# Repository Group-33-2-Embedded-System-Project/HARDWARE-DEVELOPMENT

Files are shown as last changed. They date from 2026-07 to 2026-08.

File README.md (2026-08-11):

# Smart Coop Predator Deterrent — ESP32 Edition

A self-contained, WiFi-connected predator deterrent for chicken coops. The ESP32 runs a local HTTP + WebSocket API — **no backend, no MQTT broker, no cloud**. A companion mobile app connects directly to the device over your home WiFi.

The system arms automatically at night, watches for motion with radar + PIR, escalates through CLEAR → CAUTION → DANGER → ALERT, and fires a two-tone siren + red strobe + 8×8 matrix display. Everything is visible on the device itself; the app is for remote monitoring and control.

---

## 1. Project Files

| File | Purpose |
|---|---|
| `diagram.json` | Wokwi circuit diagram (ESP32 + all sensors/actuators wired) |
| `smart_coop_deterrent.ino` | Main firmware |
| `libraries.txt` | Wokwi library auto-install list |
| `scpd-mobile/App.js` | React Native / Expo companion app |
| `README.md` | This file |

All four files must sit in the **same project folder** (whether that's a Wokwi project
or a local Arduino sketch folder).

### Revised 3D enclosure

The original root-level STL exports are legacy files and are substantially oversized.
The editable compact replacement is in [`enclosure/`](enclosure/):
`smart_coop_enclosure.scad` generates a 104 × 78 × 30 mm base and a matching fitted
lid. The design uses 1.8 mm walls, a 1.6 mm floor/lid, M2.5 screw bosses, a
MAX7219 display aperture, a cable exit, and print-friendly ventilation. Component
envelopes, tolerances, and export instructions are in `enclosure/DIMENSIONS.md`.

---

## 2. Hardware / Bill of Materials
---

## 2. Hardware / Bill of Materials

- ESP32 DevKit V1
- RCWL-0516 microwave radar sensor
- HC-SR501 (or similar) PIR motion sensor
- LDR module with digital `DO` output (LM393-style)
- 8×8 LED matrix — **MAX7219 / 1088AS** (DIN → GPIO 5, CS → GPIO 17, CLK → GPIO 18)
- Passive buzzer → GPIO 26
- Red alert LED (through 220 Ω) → GPIO 25
- WiFi status LED → GPIO 2
- Pushbutton (manual trigger) → GPIO 32
- 5 V regulated supply for the matrix (≥ 4 A recommended); common GND with ESP32

> **Note:** The matrix is driven with a small built-in MAX7219 `shiftOut` driver — no extra NeoPixel/Adafruit_NeoPixel library needed. A 74AHCT125 level shifter on the matrix data line is recommended for reliable real-world operation.

---

## 3. Pinout (ESP32 DevKit V1)

| Component | Pin | Notes |
|---|---|---|
| RCWL-0516 OUT | GPIO 4 | 3.3 V-tolerant radar output |
| PIR OUT | GPIO 27 | digital input |
| Pushbutton | GPIO 32 | `INPUT_PULLUP`, other leg to GND |
| LDR DO | GPIO 34 | digital input; adjust the module trimmer for your dark threshold |
| Matrix DIN | GPIO 5 | MAX7219 data |
| Matrix CS | GPIO 17 | MAX7219 chip-select |
| Matrix CLK | GPIO 18 | MAX7219 clock |
| Buzzer | GPIO 26 | passive buzzer + GND |
| Red alert LED | GPIO 25 | through 220 Ω |
| WiFi status LED | GPIO 2 | through 220 Ω |
| Battery voltage sense | GPIO 35 | optional analog input |

---

## 4. Firmware Behavior

### 4.1 Arming
The system is **armed at night** (LDR = dark). The mobile app can also force `auto` / `on` / `off`.

### 4.2 Threat Levels

| Level | Trigger | Matrix | Red LED | Buzzer |
|---|---|---|---|---|
| **CLEAR** | No motion | Green breathing moon | OFF | OFF |
| **CAUTION** | Radar only, sustained ≥ 2 s | Yellow border + inner pulse | Solid | OFF |
| **DANGER** | PIR + radar simultaneous | Orange frame + flashing crosshair | Solid | OFF |
| **ALERT** | Deterrent actively firing | Red blinking alarm (~2 Hz) | Fast strobe | Two-tone 2.5 kHz / 1.2 kHz |
| **BOOTING** | WiFi not yet connected | Blue rotating spinner | OFF | OFF |
| **OFFLINE** | WiFi lost after connect | Normal threat glyph + blinking blue corner pixel | — | — |

- Matrix brightness auto-adjusts to ambient light (LDR): dim in darkness, bright in daylight, full during ALERT.
- Button press: manual trigger + white flash acknowledgement on matrix.
- Component toggles (radar, PIR, deterrent, matrix, buzzer) are available from the app and respected by the firmware immediately.

### 4.3 Radar hold
A detection is held for **4 seconds** (`RADAR_HOLD_MS`) after the last radar HIGH so the CAUTION state and the app’s radar dot stay visible instead of flickering off.

---

## 5. Mobile App Connection (No Backend)

The app (`scpd-mobile/App.js`) is a React Native / Expo app. It discovers and talks to the ESP32 **directly** — no cloud, no broker.

### 5.1 Discovery
1. Tries mDNS: `coop-plus.local`, `smart-coop.local` (best on iOS; Android may require manual IP).
2. Scans a few common static IPs.
3. Scans the **phone’s actual WiFi subnet** (requires `expo-network`).
4. If discovery fails, enter the ESP32’s IP manually (shown in Serial Monitor at 115200 baud).

### 5.2 Live Communication
- **HTTP REST:** `GET /api/status`, `POST /api/commands/deterrent`, `POST /api/commands/arm`, `POST /api/commands/toggle_component`, `DELETE /api/events`, `DELETE /api/events/<id>`
- **WebSocket:** `ws://<host>:80/ws` pushes live status updates.

Both run on **port 80**. The phone and ESP32 must be on the **same LAN**.

---

## 6. Quick Start

### Wokwi (simulation)
1. Open the project in Wokwi.
2. Ensure `diagram.json`, `smart_coop_deterrent.ino`, and `libraries.txt` are present.
3. Press Play. Wokwi auto-installs the listed libraries.

### Real hardware (Arduino IDE / CLI)
1. Install the ESP32 board package (Espressif Systems).
2. Select **ESP32 Dev Module** (or your board).
3. Place `smart_coop_deterrent.ino` in a folder named `smart_coop_deterrent`.
4. Edit the WiFi block at the top of the sketch with your SSID and password.
5. Upload; open Serial Monitor at **115200 baud** to watch the connection logs and the printed local IP.

### Mobile app
```bash
cd scpd-mobile
npx expo install expo-network   # required for subnet-aware discovery
npx expo start
```
Scan the QR with Expo Go (or run on a simulator). Tap **Connect**; if auto-detect misses, type the ESP32’s IP manually.

---

## 7. Serial Test Commands

With the ESP32 connected to Serial Monitor (`115200` baud, `NL + CR` or line ending set appropriately):

| Command | Effect |
|---|---|
| `help` | Print this menu |
| `status` | Full system status report |
| `led` | Blink the red alert LED 3× |
| `buzzer` | 2-second buzzer test |
| `matrix` | Cycle through all matrix states |
| `telemetry` | Live sensor stream |
| `ldr_calib` | Calibrate LDR dark threshold |

---

## 8. Troubleshooting

| Symptom | Likely cause / fix |
|---|---|
| App can’t discover the device | Phone and ESP32 are on different subnets, or AP/client isolation is on. Enter the ESP32’s IP manually (shown in Serial Monitor). |
| App connects but “Connecting…” flickers / kicks back to Home | Auto-reconnect now runs silently in the background; reload the app. If it persists, the firmware’s WiFi is flapping — check signal strength. |
| Matrix is blank / wrong size | Confirm DIN/CS/CLK wiring and that the matrix is powered from a separate 5 V supply, not the ESP32’s USB pin. |
| Buzzer quiet or clicking | Passive buzzer on GPIO 26 + GND. If using an active buzzer, the pitch sweep won’t work — swap to passive. |
| Deterrent never fires | Check `armed` state (Serial `status`), LDR dark threshold, and that radar/PIR toggles are enabled in the app. |
| Events/activities not clearing | Use the trash icon on individual events, or the **Clear** button in History. Both now hit firmware endpoints and refresh automatically. |

---

## 9. Design Notes (for the poster / reviewers)

- **No cloud dependency.** The ESP32 hosts its own API; the phone talks to it directly. If the internet goes down, the coop still works locally.
- **Sensors are toggleable.** Radar, PIR, deterrent, matrix, and buzzer can all be switched off from the app — useful for testing or quiet hours.
- **8×8 matrix is the primary local HCI.** Color code: green = safe, yellow = caution, orange = danger, red = alert, blue = booting/offline. The red LED stays solid for any active threat and strobes only while the siren fires.
- **Radar hold = 4 s.** A single detection lingers on the display and in the app long enough to be useful, instead of vanishing after one sensor pulse.

---

## 10. Possible Future Improvements

- TLS-encrypted API (`WiFiServerSecure`) for production.
- OTA firmware updates.
- Battery + solar monitoring if the coop isn’t near a wall outlet.
- Per-animal deterrent patterns if certain predators prove more persistent.
- Local SD-card event logging as a backup to the app.

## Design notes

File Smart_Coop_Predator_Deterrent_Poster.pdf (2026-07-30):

# SMART COOP PREDATOR DETERRENT

# An ESP32-Based Automated Sensing and Deterrent System for Backyard Poultry Protection

## [Team Member Name(s)] • [Institution / Department] • [Course / Event] • [Date]

# PROJECT OVERVIEW

Small-scale poultry keepers regularly lose chickens to nighttime predators — the loss is sudden, largely unwitnessed, and hard to prevent with fencing alone. This project implements a self-contained, low-cost monitoring and deterrent unit built around an ESP32 microcontroller. The system automatically arms itself after dark using ambient light sensing, detects motion in the coop with a PIR sensor, and responds within a second with a bright light and audible siren — while also publishing live status and alerts over MQTT so an owner can monitor the coop remotely and trigger the deterrent manually from anywhere.

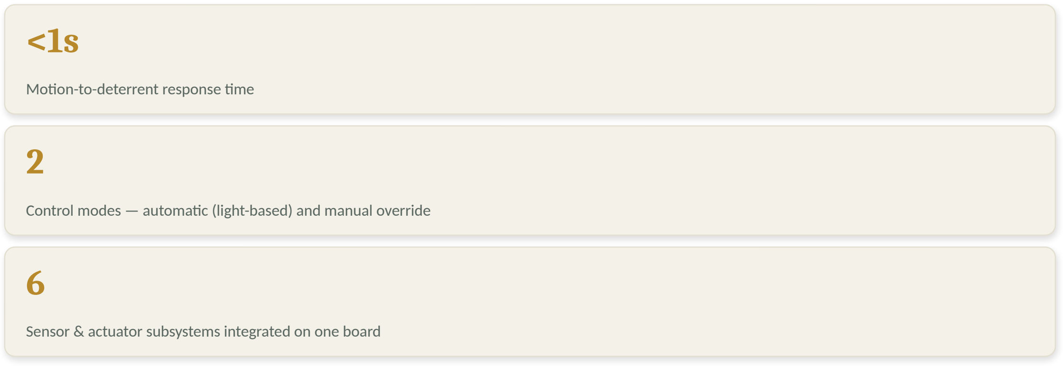
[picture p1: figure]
Motion-to-deterrent response time 2

Control modes — automatic (light-based) and manual override

Sensor & actuator subsystems integrated on one board

# DESIGN GOALS

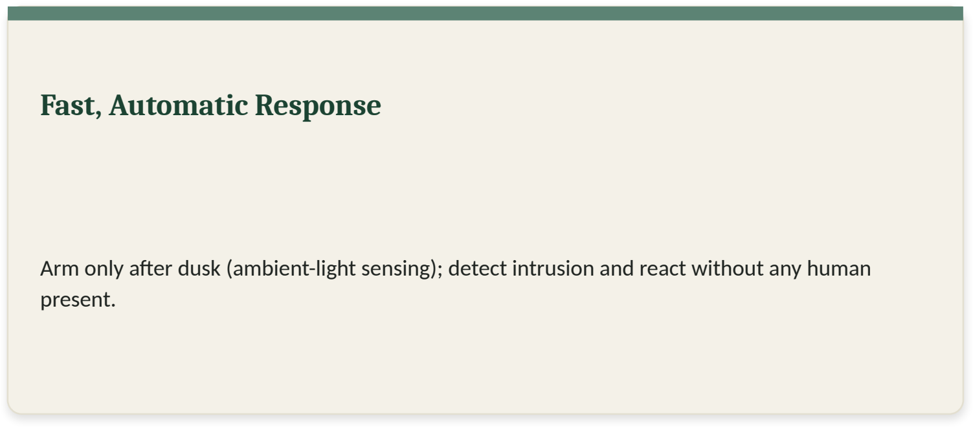
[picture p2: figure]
Fast, Automatic Response; present.

Arm only after dusk (ambient-light sensing); detect intrusion and react without any human

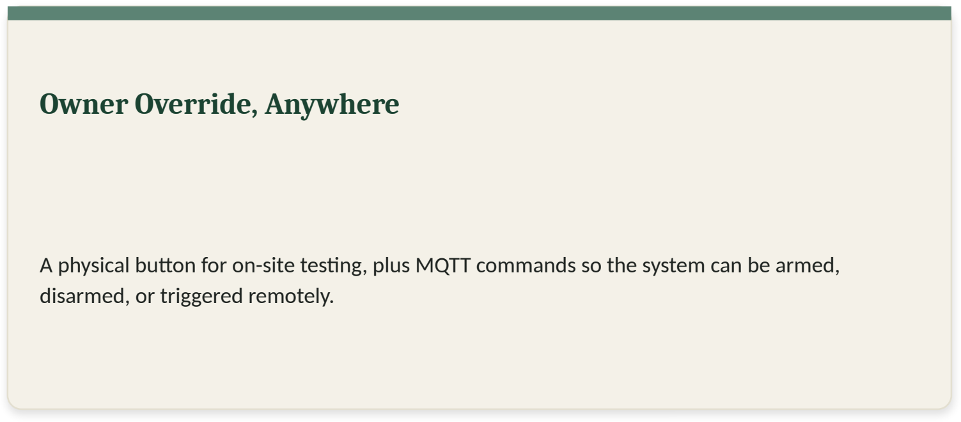
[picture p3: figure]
Owner Override, Anywhere; disarmed, or triggered remotely.

A physical button for on-site testing, plus MQTT commands so the system can be armed,

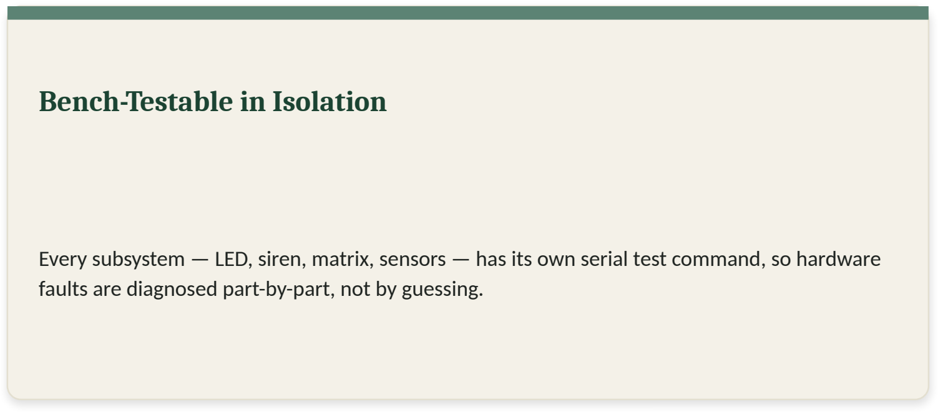
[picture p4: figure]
Bench-Testable in Isolation

Every subsystem — LED, siren, matrix, sensors — has its own serial test command, so hardware faults are diagnosed part-by-part, not by guessing.

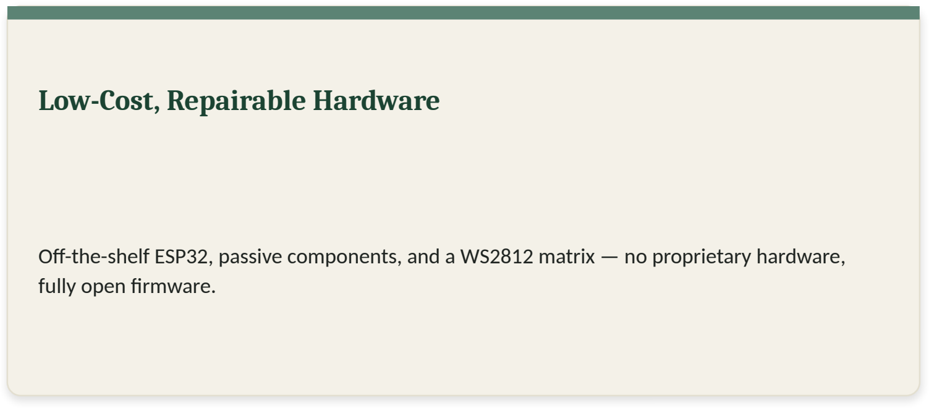
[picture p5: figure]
Low-Cost, Repairable Hardware; fully open firmware.

Off-the-shelf ESP32, passive components, and a WS2812 matrix — no proprietary hardware,

# SYSTEM ARCHITECTURE

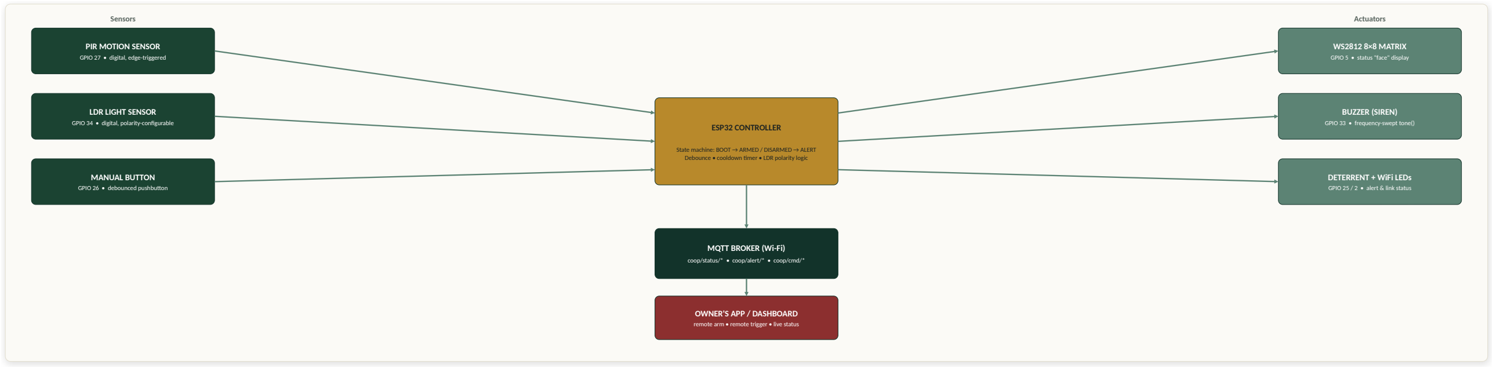
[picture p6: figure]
PIR MOTION SENSOR; GPIO 27 • digital, edge-triggered; LDR LIGHT SENSOR; GPIO 34 • digital, polarity-configurable; MANUAL BUTTON; GPIO 26 • debounced pushbutton; ESP32 CONTROLLER; WS2812 8×8 MATRIX; GPIO 5 • status "face" display; BUZZER (SIREN); GPIO 33 • frequency-swept tone(); DETERRENT + WiFi LEDs; GPIO 25 / 2 • alert & link status; MQTT BROKER (Wi-Fi); coop/status/* • coop/alert/* • coop/cmd/*; OWNER'S APP / DASHBOARD; Sensors; Actuators

State machine: BOOT → ARMED / DISARMED → ALERT Debounce • cooldown timer • LDR polarity logic

remote arm • remote trigger • live status

# KEY FEATURES

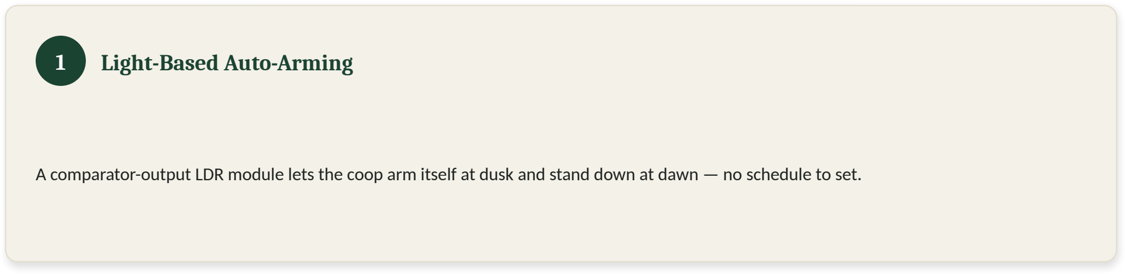
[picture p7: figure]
1 Light-Based Auto-Arming

A comparator-output LDR module lets the coop arm itself at dusk and stand down at dawn — no schedule to set.

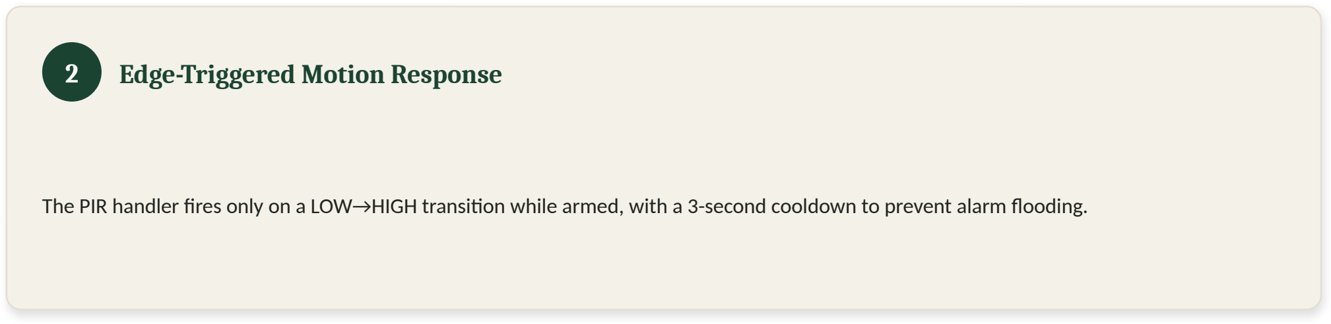
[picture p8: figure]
2 Edge-Triggered Motion Response

The PIR handler fires only on a LOW→HIGH transition while armed, with a 3-second cooldown to prevent alarm flooding.

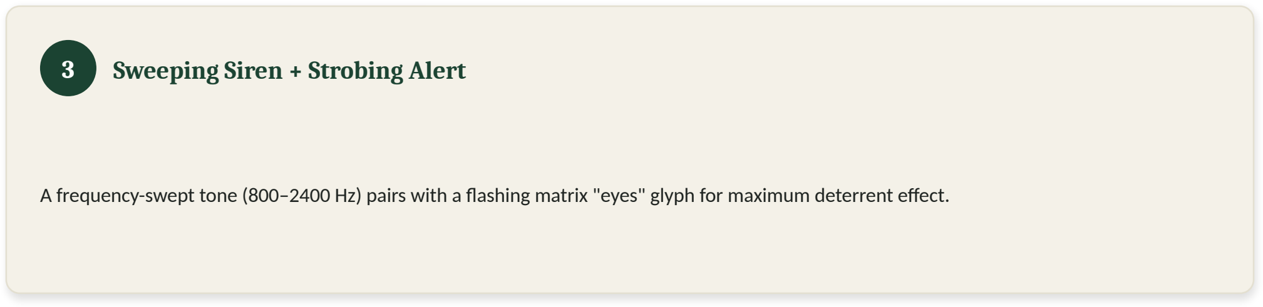
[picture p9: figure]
3 Sweeping Siren + Strobing Alert

A frequency-swept tone (800–2400 Hz) pairs with a flashing matrix "eyes" glyph for maximum deterrent effect.

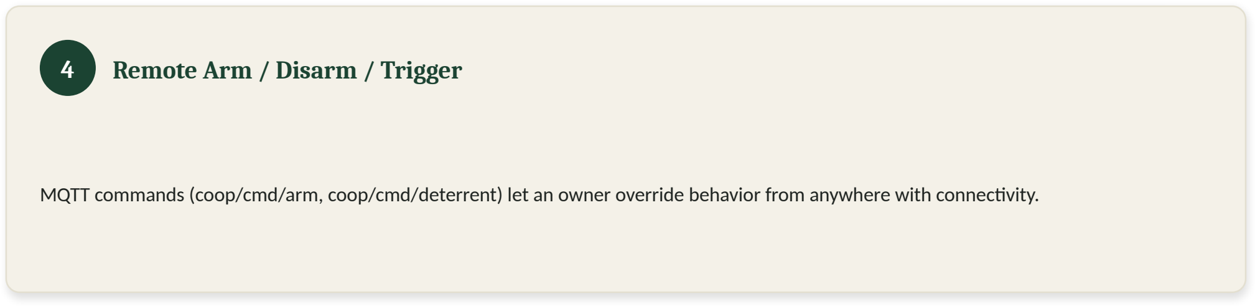
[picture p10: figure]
4 Remote Arm / Disarm / Trigger

MQTT commands (coop/cmd/arm, coop/cmd/deterrent) let an owner override behavior from anywhere with connectivity.

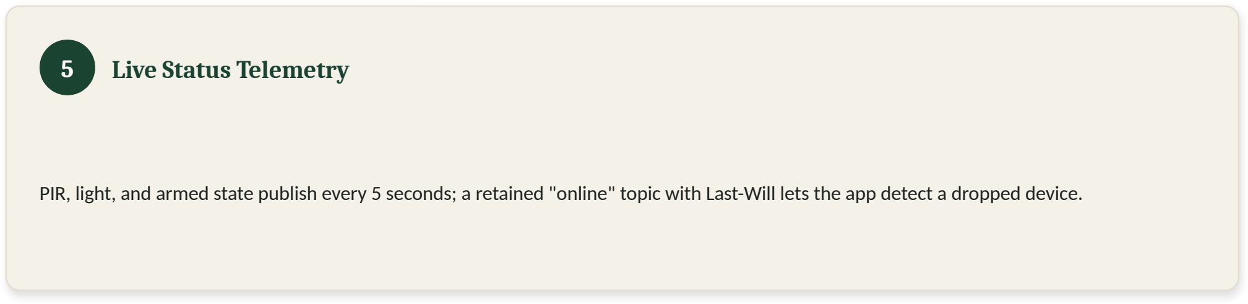
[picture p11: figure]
5 Live Status Telemetry

PIR, light, and armed state publish every 5 seconds; a retained "online" topic with Last-Will lets the app detect a dropped device.

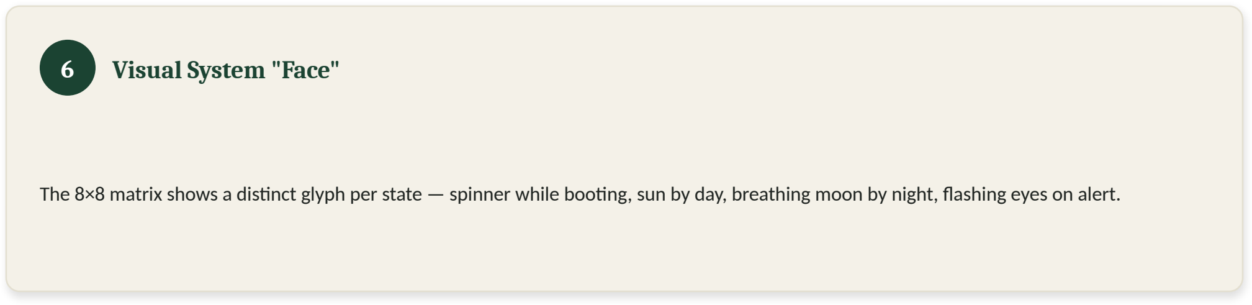
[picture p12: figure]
6 Visual System "Face"

The 8×8 matrix shows a distinct glyph per state — spinner while booting, sun by day, breathing moon by night, flashing eyes on alert.

# TECHNICAL SPECIFICATIONS

### Hardware & Pin Map

Component | GPIO | Notes
PIR motion sensor | GPIO 27, digital in | 3.3V logic only — verify module output
Manual button | GPIO 26, INPUT_PULLUP | Debounced, 50 ms window
LDR light module | GPIO 34, digital in | Comparator output, polarity configurable
WS2812 8×8 matrix | GPIO 5, DIN | 64 pixels — VDD, GND, DIN required
Buzzer | GPIO 33 | Passive tone() or active-module fallback
Deterrent LED (red) | GPIO 25 | Digital out, dimmed on ack overlay
Wi-Fi status LED (green) | GPIO 2 | Blink = connecting, solid = online

### MQTT Topic Map

MQTT Topic | Direction | Payload / Purpose
coop/status/pir | publish | "0" / "1" — live motion state
coop/status/light | publish | "0" / "1" — raw LDR reading
coop/status/armed | publish | "0" / "1" — current arm state
coop/alert/predator | publish | "1" — fires once per trigger
coop/status/online | publish (LWT) | retained; "0" on disconnect
coop/cmd/deterrent | subscribe | "trigger" — force-fire remotely
coop/cmd/arm | subscribe | "auto" / "on" / "off"

# TESTING, VALIDATION & FUTURE WORK

### Bench-Test Methodology

- Serial test console isolates each subsystem before integration — led, buzzer, buzzer2, matrix, status commands
- LDR polarity verified empirically per-unit (no fixed "dark = HIGH" assumption across comparator modules)
- Deterrent cooldown (3 s) and debounce (50 ms) tuned against false triggers on the physical bench unit
- Wiring and power faults (e.g. matrix requiring a common GND, not just VDD + DIN) documented and diagnosed live during build

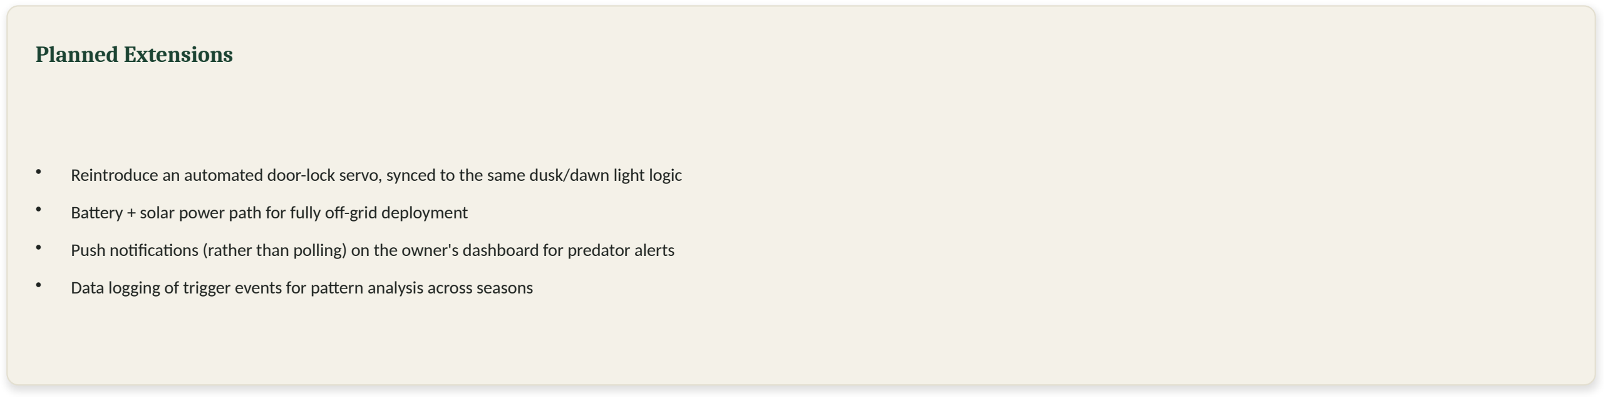
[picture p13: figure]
Planned Extensions

- Reintroduce an automated door-lock servo, synced to the same dusk/dawn light logic
- Battery + solar power path for fully off-grid deployment
- Push notifications (rather than polling) on the owner's dashboard for predator alerts
- Data logging of trigger events for pattern analysis across seasons

The system demonstrates that a single low-cost microcontroller can combine light-aware arming, motion-triggered deterrence, and remote MQTT monitoring into one coherent, independently testable unit — a practical, extensible foundation for automated small-scale coop protection.

Smart Coop Predator Deterrent — ESP32 / PubSubClient / Adafruit NeoPixel — Firmware v3

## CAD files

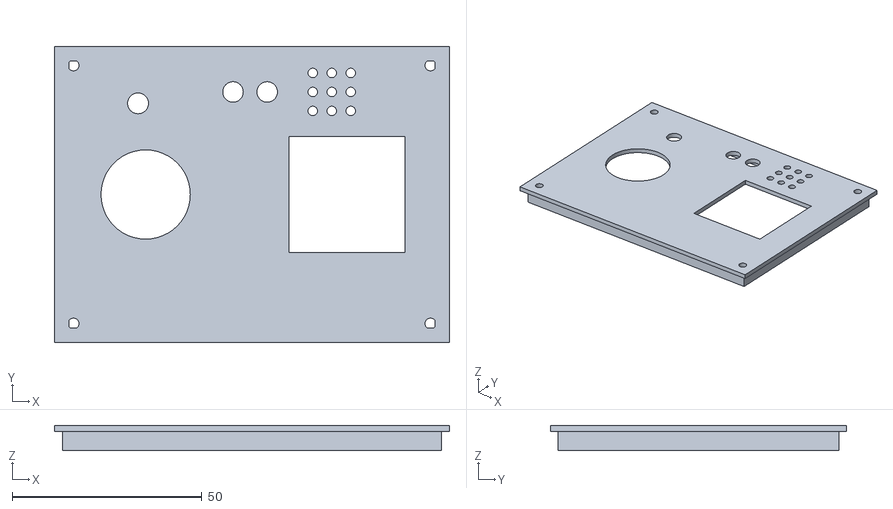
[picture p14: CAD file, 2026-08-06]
coop_lid_v4_corrected.stl
104.0 x 78.0 x 6.60

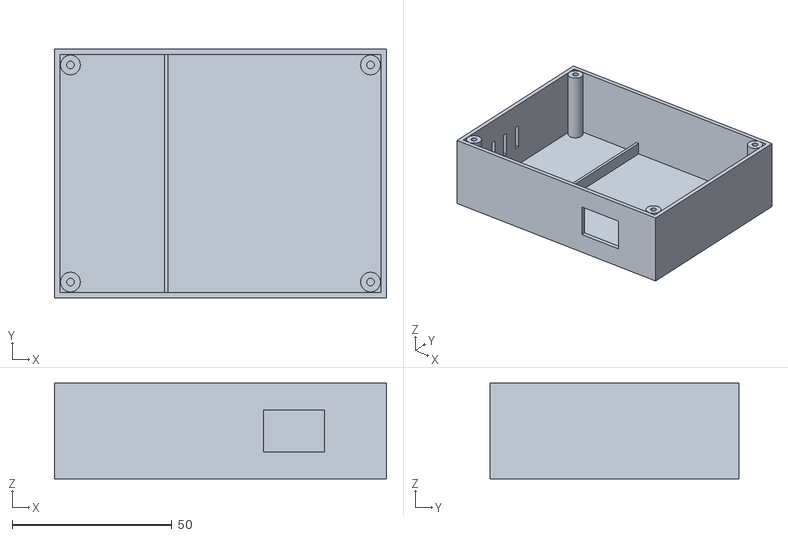
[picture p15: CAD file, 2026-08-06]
coop_enclosure_BASE.stl
104.0 x 78.0 x 30.0

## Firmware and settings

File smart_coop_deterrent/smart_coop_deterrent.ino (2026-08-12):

/*
  ==========================================================
   SMART COOP PREDATOR DETERRENT — ESP32 Firmware (v4)
   ENHANCED: Full 8x8 LED Matrix + RCWL-0516 Radar Support
  ==========================================================
  
  Hardware Setup:
    - RCWL-0516 Radar        -> GPIO 4  (3.3V OUT signal)
    - PIR Motion Sensor      -> GPIO 27 (3.3V OUT signal)
  - Push Button            -> GPIO 32 (INPUT_PULLUP with 10kΩ resistor)
  - LDR Module (DO pin)    -> GPIO 34 (Digital: dark detection)
  - 8x8 LED Matrix         -> GPIO 5 (DIN), GPIO 17 (CS), GPIO 18 (CLK)
  - Buzzer                 -> GPIO 26 (Active or passive) + GND
    - Red Alert LED          -> GPIO 25 (Status)
    - WiFi Status LED        -> GPIO 2  (Connection indicator)

  KEY IMPROVEMENTS IN v4:
    ✅ RCWL-0516 radar with dual-trigger support (radar + PIR both monitored)
    ✅ 8x8 LED matrix displays detailed threat visualization
    ✅ Threat level system (CLEAR → CAUTION → DANGER → ALERT)
    ✅ Brightness auto-adjust based on ambient light (LDR feedback)
    ✅ Enhanced siren pattern (eco-mode + full-alarm variations)
    ✅ Separate tracking for radar & PIR events
    ✅ Better state machine with threat escalation
    ✅ Serial debug with live sensor telemetry
    ✅ Local HTTP + WebSocket API (mobile app connects directly, no backend)
    ✅ Button ACK with visual confirmation

   THREAT LEVEL SYSTEM — 8x8 MATRIX HCI LANGUAGE
   -------------------------------------------------------------
   The 1088AS module is a SINGLE-COLOUR (red) matrix, so states are
   communicated by SHAPE + MOTION, never by hue. Each state has a distinct,
   learnable glyph and a blink cadence that rises with urgency, so the device
   can be read at a glance and from a distance (good HCI practice):

     BOOTING        → rotating perimeter dot          (working…)
     DISARMED       → hollow ring  "○"   steady, dim   (inactive / neutral)
     CLEAR (armed)  → shield      "🛡"   steady, breathing (protected, quiet)
     CAUTION (L1)   → "?"         slow pulse 0.6 Hz    (radar saw something)
     DANGER  (L2)   → "!"         blink 2.5 Hz         (motion confirmed)
     ALERT   (L3)   → "✕"         fast blink 4 Hz      (deterrent firing)
     OFFLINE        → blue corner pixel blinking        (link lost)

   Urgency mapping is monotonic (○ → 🛡 → ? → ! → ✕) so operators build one
   mental model: "more pixels moving faster = more danger".
   Red status LED: solid for any active threat, strobing while the siren fires.


  ==========================================================
*/

#include <WiFi.h>
#include <ESPmDNS.h>
#include <mbedtls/base64.h>
#include <mbedtls/sha1.h>
// Using a small MAX7219 driver (shiftOut) instead of LedControl — compatible with ESP32

// ==================== USER CONFIG ====================
const char* WIFI_SSID     = "P4X";
const char* WIFI_PASSWORD = "dvorack1844l5";

// ==================== PIN DEFINITIONS ====================
#define PIN_RADAR      4
#define PIN_PIR        27
#define PIN_BUTTON     32   // moved off 26 (now the buzzer) to avoid conflict
#define PIN_LDR        34
#define PIN_MATRIX_DIN 5
#define PIN_MATRIX_CS  17
#define PIN_MATRIX_CLK 18
#define PIN_BUZZER     26   // buzzer + GND (matches working test wiring)
// Buzzer is driven via a dedicated LEDC channel so we can sweep frequency
// with ledcSetup() — which reconfigures the timer WITHOUT detaching the pin.
// Repeated tone() calls on ESP32 disconnected the pin every step, which caused
// the clicks/glitches and dropped perceived volume.
#define BUZZER_LEDC_CHANNEL 0
#define BUZZER_LEDC_RES     10      // 10-bit resolution → smooth pitch sweep
#define BUZZER_DUTY         512     // 50% of 1024 → full square wave (loudest)
#define PIN_LED_RED    25
#define PIN_LED_WIFI   2
#define PIN_BATTERY    35

// ==================== CONFIGURATION ====================
#define MATRIX_ROWS 8
#define MATRIX_COLS 8
#define NUM_PIXELS (MATRIX_ROWS * MATRIX_COLS)

#define LDR_DARK_WHEN_HIGH true  // Set after testing YOUR module

#define DETERRENT_DURATION_MS 5000
#define RADAR_CAUTION_MS 2000    // Time radar alone triggers caution
#define RADAR_DEBOUNCE_MS 80     // Debounce / stability window for RCWL-0516
#define RADAR_HOLD_MS 4000       // Keep "radar detected" lit this long after last HIGH
#define TRIGGER_COOLDOWN_MS 3000
#define WIFI_RETRY_INTERVAL_MS 30000
#define BUTTON_DEBOUNCE_MS 50
#define BUTTON_ACK_MS 300
#define BUTTON_ACK_BRIGHTNESS 40

#define SIREN_HIGH_HZ 2500   // high tone of the two-tone alarm
#define SIREN_LOW_HZ  1200   // low tone of the two-tone alarm
#define SIREN_TONE_MS 350    // duration of each tone before switching

// ==================== THREAT LEVELS ====================
enum ThreatLevel {
  THREAT_CLEAR = 0,      // No motion
  THREAT_CAUTION = 1,    // Radar only
  THREAT_DANGER = 2,     // PIR + Radar
  THREAT_ALERT = 3       // Full deterrent active
};

// ==================== SYSTEM STATE ====================
enum SystemState { 
  STATE_BOOTING,
  STATE_DISARMED_IDLE,
  STATE_ARMED_CLEAR,
  STATE_ARMED_CAUTION,
  STATE_ARMED_DANGER,
  STATE_ALERT
};

// ==================== GLOBAL OBJECTS ====================
// Allow several concurrent clients. The mobile app's subnet scan (and its
// WebSocket + periodic HTTP status/commands) can open multiple sockets at once;
// the ESP32 WiFiServer default of a single client causes connection-refused and
// makes discovery miss the device.
WiFiServer apiServer(80, 8);


struct LocalCommandEntry {
  uint32_t id;
  String type;
  String payload;
  String requestedBy;
  String status;
  unsigned long requestedAt;
};

static const int LOCAL_COMMAND_LOG_SIZE = 16;
LocalCommandEntry localCommands[LOCAL_COMMAND_LOG_SIZE];
int localCommandCount = 0;
uint32_t localCommandNextId = 1;

struct LocalEventEntry {
  uint32_t id;
  String type;        // "pir", "radar", "deterrent", "arm", "threat"
  String title;
  String details;
  int threatLevel;
  unsigned long timestamp;
};

static const int LOCAL_EVENT_LOG_SIZE = 32;
LocalEventEntry localEvents[LOCAL_EVENT_LOG_SIZE];
int localEventCount = 0;
uint32_t localEventNextId = 1;
bool mdnsStarted = false;
bool apiServerStarted = false;
WiFiClient wsClient;
bool wsClientConnected = false;
String wsHandshakeBuffer;
String lastLocalStatusSignature;

// Small MAX7219 driver using shiftOut so it works on ESP32 without AVR headers.
// Provides a subset of the Adafruit_NeoPixel-like API used by the rest of this
// sketch (setPixelColor, setBrightness, show, Color). This keeps the existing
// drawing functions intact while driving a single 8x8 MAX7219 (1088AS) module.
//
// Drawing is double-buffered: setPixelColor() only touches the off-screen
// 'rows' framebuffer, and show() pushes all 8 rows in one pass. This removes
// the clear-then-redraw flicker the previous immediate-write version had, which
// is important for legible, steady HCI feedback.
class MatrixWrapper {
  public:
    MatrixWrapper(int dataPin, int clkPin, int csPin, int devices): mosiPin(dataPin), clkPin(clkPin), csPin(csPin), devices(devices), intensity(8) {
      for (int i = 0; i < 8; ++i) rows[i] = 0;
    }

    void begin() {
      pinMode(mosiPin, OUTPUT);
      pinMode(clkPin, OUTPUT);
      pinMode(csPin, OUTPUT);
      digitalWrite(csPin, HIGH);

      // Initialize MAX7219 registers
      writeRegister(0x09, 0x00); // Decode mode: none
      writeRegister(0x0B, 0x07); // Scan limit: 0-7 (all digits)
      writeRegister(0x0C, 0x01); // Shutdown register: normal operation
      writeRegister(0x0F, 0x00); // Display test: off
      setIntensity(map(60, 0, 255, 0, 15));
      clear();
      flush(); // push the cleared buffer to the hardware
    }

    void clear() {
      for (int i = 0; i < 8; ++i) rows[i] = 0x00;
    }

    // Accept 0-255 like NeoPixel and map to MAX7219 0-15
    void setBrightness(int b) {
      if (b < 0) b = 0; if (b > 255) b = 255;
      intensity = map(b, 0, 255, 0, 15) & 0x0F;
      setIntensity(intensity);
    }

    // Push the framebuffer to the MAX7219 in a single pass (no flicker).
    void show() { flush(); }

    // index: 0..63 mapping row-major (row*8 + col)
    void setPixelColor(int index, uint32_t color) {
      int row = index / MATRIX_COLS;
      int col = index % MATRIX_COLS;
      if (row < 0 || row >= MATRIX_ROWS || col < 0 || col >= MATRIX_COLS) return;

      if (color != 0) rows[row] |= (1 << col);
      else rows[row] &= ~(1 << col);
    }

    // Create a nonzero color when any component > 0 so existing code can use matrix.Color(r,g,b)
    uint32_t Color(int r, int g, int b) {
      (void)r; (void)g; (void)b;
      return (r || g || b) ? 1 : 0;
    }

  private:
    int mosiPin;
    int clkPin;
    int csPin;
    int devices;
    uint8_t rows[8];
    int intensity;

    void writeRegister(uint8_t reg, uint8_t data) {
      digitalWrite(csPin, LOW);
      // MAX7219 expects two bytes: register then data
      shiftOut(mosiPin, clkPin, MSBFIRST, reg);
      shiftOut(mosiPin, clkPin, MSBFIRST, data);
      digitalWrite(csPin, HIGH);
    }

    void setIntensity(int val) { writeRegister(0x0A, val & 0x0F); }

    // Write every row of the framebuffer once. Cheap (8 SPI pairs) and avoids
    // the partial-frame tearing you get from per-pixel hardware writes.
    void flush() {
      for (int i = 0; i < 8; ++i) writeRegister(i + 1, rows[i]);
    }
};

// Instantiate the wrapper with the configured pins (single device)
MatrixWrapper matrix(PIN_MATRIX_DIN, PIN_MATRIX_CLK, PIN_MATRIX_CS, 1);

// ==================== SYSTEM STATE VARIABLES ====================
SystemState currentState = STATE_BOOTING;
ThreatLevel currentThreatLevel = THREAT_CLEAR;

bool armed = false;
bool armOverride = false;
bool armOverrideValue = false;

bool deterrentActive = false;
unsigned long deterrentStartTime = 0;
unsigned long lastTriggerTime = 0;
unsigned long lastWiFiAttempt = 0;

// Sensor state tracking
int lastPirState = LOW;
int lastRadarState = LOW;           // last stable radar state used by logic

// For radar debouncing (RCWL-0516 can be noisy) — preserve raw reading and timing
int lastRadarRaw = LOW;             // most recent raw sample
unsigned long lastRadarRawChange = 0; // when raw sample last changed
int stableRadarState = LOW;         // debounced/stable radar state

unsigned long radarActiveStart = 0;
bool radarCautionTriggered = false;
unsigned long radarHoldUntil = 0;   // keeps "radar detected" lit for RADAR_HOLD_MS
bool lastRadarPresent = false;      // edge tracking for the held state

// Button debouncing
int lastButtonReading = HIGH;
int stableButtonState = HIGH;
unsigned long lastButtonChangeTime = 0;

// Button ACK animation
bool buttonAckActive = false;
unsigned long buttonAckStart = 0;

// Matrix brightness control (auto-adjusted by LDR)
int matrixBrightness = 60;

// Battery monitoring
float batteryVoltage = 0.0;
int batteryPercent = 0;

// Component toggles
bool radarEnabled = true;
bool pirEnabled = true;
bool deterrentEnabled = true;
bool matrixEnabled = true;
bool buzzerEnabled = true;

// ==========================================================
// SETUP
// ==========================================================
void setup() {
  Serial.begin(115200);
  delay(1000);
  
  Serial.println("\n╔══════════════════════════════════════╗");
  Serial.println("║  SMART COOP v4 - ENHANCED FIRMWARE   ║");
  Serial.println("║  Radar + PIR + 8x8 Matrix Display    ║");
  Serial.println("╚══════════════════════════════════════╝\n");

  // Initialize pins
  pinMode(PIN_RADAR, INPUT);
  pinMode(PIN_PIR, INPUT);
  pinMode(PIN_BUTTON, INPUT_PULLUP);
  pinMode(PIN_LDR, INPUT);
  pinMode(PIN_BUZZER, OUTPUT);
  pinMode(PIN_LED_RED, OUTPUT);
  pinMode(PIN_LED_WIFI, OUTPUT);
  pinMode(PIN_BATTERY, INPUT);

  digitalWrite(PIN_BUZZER, LOW);
  digitalWrite(PIN_LED_RED, LOW);
  digitalWrite(PIN_LED_WIFI, LOW);

  // Configure the buzzer LEDC channel ONCE. We keep the pin attached and only
  // re-run ledcSetup() with a new frequency from here on (no pin detach), so the
  // siren sweep stays continuous and click-free.
  ledcSetup(BUZZER_LEDC_CHANNEL, (double)SIREN_LOW_HZ, BUZZER_LEDC_RES);
  ledcAttachPin(PIN_BUZZER, BUZZER_LEDC_CHANNEL);
  ledcWrite(BUZZER_LEDC_CHANNEL, 0); // start silent

  // Initialize 8x8 LED matrix
  matrix.begin();
  matrix.clear();
  matrix.setBrightness(60);
  matrix.show();

  // WiFi setup — station (infrastructure) mode. This is the architecture that
  // was connecting reliably; auto-reconnect recovers the link if the router
  // drops it. (A SoftAP fallback was tried but interfered with the station link
  // on several boards, leaving the device stuck booting and unreachable.)
  currentState = STATE_BOOTING;
  WiFi.mode(WIFI_STA);
  WiFi.setAutoReconnect(true);
  startWiFiConnection();

  apiServer.begin();
  apiServerStarted = true;
  Serial.println("✓ Local API server started on port 80");

  Serial.println("✓ Hardware initialized");
  Serial.println("✓ Type 'help' for serial test commands\n");
}

// ==========================================================
// MAIN LOOP
// ==========================================================
void loop() {
  handleSerialTestMode();
  handleNetwork();
  handleLocalApi();

  bool isDark = readIsDark();
  armed = armOverride ? armOverrideValue : isDark;

  handleRadarSensor();
  handlePIRSensor();
  handleButton();
  updateDeterrent();
  updateThreatLevel();
  updateIndicatorLeds();
  updateSystemStateIfIdle();
  // Update brightness BEFORE rendering so per-state breathing effects can change global intensity
  updateMatrixBrightness();
  updateMatrixDisplay();

  unsigned long now = millis();

  // Read battery voltage every 30 seconds
  static unsigned long lastBatteryRead = 0;
  if (now - lastBatteryRead > 30000) {
    batteryVoltage = readBatteryVoltage();
    batteryPercent = batteryPercentFromVoltage(batteryVoltage);
    lastBatteryRead = now;
  }
}

// ==========================================================
// LOCAL API (HTTP + WebSocket)
// ==========================================================
String jsonEscape(const String& value) {
  String out;
  out.reserve(value.length() + 8);
  for (size_t i = 0; i < value.length(); ++i) {
    char c = value[i];
    switch (c) {
      case '\\': out += "\\\\"; break;
      case '"':  out += "\\\""; break;
      case '\n': out += "\\n"; break;
      case '\r': break;
      case '\t': out += "\\t"; break;
      default: out += c; break;
    }
  }
  return out;
}

String threatLevelLabel(ThreatLevel level) {
  switch (level) {
    case THREAT_CLEAR: return "clear";
    case THREAT_CAUTION: return "caution";
    case THREAT_DANGER: return "danger";
    case THREAT_ALERT: return "alert";
  }
  return "clear";
}

String commandEntryJson(const LocalCommandEntry& entry) {
  String json = "{";
  json += "\"id\":" + String(entry.id) + ",";
  json += "\"type\":\"" + jsonEscape(entry.type) + "\",";
  json += "\"payload\":\"" + jsonEscape(entry.payload) + "\",";
  json += "\"requestedBy\":\"" + jsonEscape(entry.requestedBy) + "\",";
  json += "\"status\":\"" + jsonEscape(entry.status) + "\",";
  json += "\"requestedAt\":" + String(entry.requestedAt);
  json += "}";
  return json;
}

String commandsJson() {
  String json = "[";
  for (int i = 0; i < localCommandCount; ++i) {
    if (i) json += ",";
    json += commandEntryJson(localCommands[i]);
  }
  json += "]";
  return json;
}

String statusSignature() {
  String sig;
  sig.reserve(64);
  sig += String(armed ? 1 : 0);
  sig += '|';
  sig += String(lastPirState);
  sig += '|';
  sig += String(lastRadarState);
  sig += '|';
  sig += String(readIsDark() ? 1 : 0);
  sig += '|';
  sig += String(currentThreatLevel);
  sig += '|';
  sig += String(deterrentActive ? 1 : 0);
  sig += '|';
  sig += String(localCommandCount);
  sig += '|';
  sig += String(WiFi.status() == WL_CONNECTED ? 1 : 0);
  return sig;
}

String eventEntryJson(const LocalEventEntry& entry) {
  String json = "{";
  json += "\"id\":" + String(entry.id) + ",";
  json += "\"type\":\"" + jsonEscape(entry.type) + "\",";
  json += "\"title\":\"" + jsonEscape(entry.title) + "\",";
  json += "\"details\":\"" + jsonEscape(entry.details) + "\",";
  json += "\"threatLevel\":" + String(entry.threatLevel) + ",";
  json += "\"timestamp\":" + String(entry.timestamp);
  json += "}";
  return json;
}

String eventsJson() {
  String json = "[";
  for (int i = localEventCount - 1; i >= 0; --i) {
    if (i != localEventCount - 1) json += ",";
    json += eventEntryJson(localEvents[i]);
  }
  json += "]";
  return json;
}

void recordLocalEvent(const String& type, const String& title, const String& details, int threatLevel) {
  LocalEventEntry entry;
  entry.id = localEventNextId++;
  entry.type = type;
  entry.title = title;
  entry.details = details;
  entry.threatLevel = threatLevel;
  entry.timestamp = millis();

  if (localEventCount < LOCAL_EVENT_LOG_SIZE) {
    localEvents[localEventCount++] = entry;
  } else {
    for (int i = 1; i < LOCAL_EVENT_LOG_SIZE; ++i) {
      localEvents[i - 1] = localEvents[i];
    }
    localEvents[LOCAL_EVENT_LOG_SIZE - 1] = entry;
  }
}

void clearLocalEvents() {
  localEventCount = 0;
}

bool removeLocalEvent(uint32_t id) {
  for (int i = 0; i < localEventCount; ++i) {
    if (localEvents[i].id == id) {
      for (int j = i + 1; j < localEventCount; ++j) localEvents[j - 1] = localEvents[j];
      localEventCount--;
      return true;
    }
  }
  return false;
}

String statusJson() {
  String ip = WiFi.status() == WL_CONNECTED ? WiFi.localIP().toString() : "";
  String json = "{";
  json += "\"device\":{";
  json += "\"pir\":" + String(lastPirState == HIGH ? "true" : "false") + ",";
  json += "\"radar\":" + String(lastRadarState == HIGH ? "true" : "false") + ",";
  json += "\"light\":" + String(readIsDark() ? "true" : "false") + ",";
  json += "\"armed\":" + String(armed ? "true" : "false") + ",";
  json += "\"online\":" + String(WiFi.status() == WL_CONNECTED ? "true" : "false") + ",";
  json += "\"deterrentActive\":" + String(deterrentActive ? "true" : "false") + ",";
  json += "\"threatLevel\":" + String(currentThreatLevel) + ",";
  json += "\"threatLabel\":\"" + threatLevelLabel(currentThreatLevel) + "\",";
  json += "\"ip\":\"" + ip + "\",";
  json += "\"updatedAt\":" + String(millis()) + ",";
  json += "\"battery\":" + String(batteryPercent) + ",";
  json += "\"components\":{";
  json += "\"radar\":" + String(radarEnabled ? "true" : "false") + ",";
  json += "\"pir\":" + String(pirEnabled ? "true" : "false") + ",";
  json += "\"deterrent\":" + String(deterrentEnabled ? "true" : "false") + ",";
  json += "\"matrix\":" + String(matrixEnabled ? "true" : "false") + ",";
  json += "\"buzzer\":" + String(buzzerEnabled ? "true" : "false");
  json += "},";
  json += "\"commands\":" + commandsJson() + ",";
  json += "\"events\":" + eventsJson();
  json += "},";
  json += "\"api\":{";
  json += "\"local\":true,";
  json += "\"websocket\":true,";
  json += "\"port\":80";
  json += "}";
  json += "}";
  return json;
}

void recordLocalCommand(const String& type, const String& payload, const String& requestedBy, const String& status) {
  LocalCommandEntry entry;
  entry.id = localCommandNextId++;
  entry.type = type;
  entry.payload = payload;
  entry.requestedBy = requestedBy;
  entry.status = status;
  entry.requestedAt = millis();

  if (localCommandCount < LOCAL_COMMAND_LOG_SIZE) {
    localCommands[localCommandCount++] = entry;
  } else {
    for (int i = 1; i < LOCAL_COMMAND_LOG_SIZE; ++i) {
      localCommands[i - 1] = localCommands[i];
    }
    localCommands[LOCAL_COMMAND_LOG_SIZE - 1] = entry;
  }
}

bool removeLocalCommand(uint32_t id) {
  for (int i = 0; i < localCommandCount; ++i) {
    if (localCommands[i].id == id) {
      for (int j = i + 1; j < localCommandCount; ++j) {
        localCommands[j - 1] = localCommands[j];
      }
      localCommandCount--;
      return true;
    }
  }
  return false;
}

void clearLocalCommands() {
  localCommandCount = 0;
}

void sendHttpResponse(WiFiClient& client, int code, const String& contentType, const String& body) {
  const char* statusText = code == 200 ? "OK" : code == 201 ? "Created" : code == 202 ? "Accepted" : code == 204 ? "No Content" : code == 400 ? "Bad Request" : code == 404 ? "Not Found" : code == 500 ? "Internal Server Error" : "OK";
  client.printf("HTTP/1.1 %d %s\r\n", code, statusText);
  client.printf("Content-Type: %s\r\n", contentType.c_str());
  client.print("Access-Control-Allow-Origin: *\r\n");
  client.print("Access-Control-Allow-Headers: Content-Type\r\n");
  client.print("Access-Control-Allow-Methods: GET,POST,DELETE,OPTIONS\r\n");
  client.printf("Content-Length: %u\r\n", (unsigned)body.length());
  client.print("Connection: close\r\n\r\n");
  client.print(body);
}

void sendHttpJson(WiFiClient& client, int code, const String& body) {
  sendHttpResponse(client, code, "application/json", body);
}

String getHeaderValue(const String& headerLine) {
  int colon = headerLine.indexOf(':');
  if (colon < 0) return "";
  String value = headerLine.substring(colon + 1);
  value.trim();
  return value;
}

String stripQueryString(String path) {
  int q = path.indexOf('?');
  return q >= 0 ? path.substring(0, q) : path;
}

bool sendWsText(WiFiClient& client, const String& message) {
  if (!client.connected()) return false;

  size_t len = message.length();
  uint8_t header[10];
  size_t headerLen = 0;
  header[0] = 0x81; // FIN + text frame
  if (len < 126) {
    header[1] = len;
    headerLen = 2;
  } else if (len < 65536) {
    header[1] = 126;
    header[2] = (len >> 8) & 0xFF;
    header[3] = len & 0xFF;
    headerLen = 4;
  } else {
    return false;
  }

  client.write(header, headerLen);
  client.write((const uint8_t*)message.c_str(), len);
  return true;
}
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

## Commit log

2026-07-27 fix the cable connecttions
2026-07-27 add: the design
    [design.stl]
2026-07-30 add: software and stl file
    [coop_enclosure_BASE.stl, coop_enclosure_LID.stl, design.stl]
2026-08-04 fix: UI/UX orientation
    [coop_enclosure_LID.stl, coop_lid_v4_corrected.stl]
2026-08-06 stl files update
    [coop_enclosure_BASE.stl, coop_lid_v4_corrected.stl]
2026-08-11 refactor: remove MQTT/backend, fix toggles/events, improve HCI, stabilize app connection
    [smart_coop_deterrent.ino]
2026-08-12 Fix APK cleartext blocking + add network security config; update firmware HCI + app config
    Android: add withCleartext config plugin and network_security_config.xml so the standalone/preview APK can reach the ESP32 over plain HTTP/ws on port 80 (Expo Go worked because debug builds allow cleartext). Also commit firmware HCI refactor and app.json iOS local-network + EAS settings.
    [smart_coop_deterrent.ino]
